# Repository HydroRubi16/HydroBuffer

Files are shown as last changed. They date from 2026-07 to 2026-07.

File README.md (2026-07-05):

# HydroBuffer
A Klipper based buffer to feed, unload and synchronize filament delivery to the toolhead  


The buffer consists of four parts:  
+ The housing (designed by me)  
+ Springloaded Turtle Neck, origninally modified by jakepfake, then modified by me for the buffer  
+ [Dual-Sensor WWBMG by DWTAS](https://github.com/Armchair-Heavy-Industries/A4T/tree/main/STL/WW-BMG%20for%20A4T/Dual%20Sensor)
+ A macro of some sort

*BOM*  
|Thing|Quantity|Notes|
|---|---|---|
|ECAS04|2|Need another for WWBMG, but follow that BOM|  
|Omron df2-l|2| Need another 2 for WWBMG, but follow that BOM|
|M3 heatsets|5| |
|M3 Square nuts|2|Need another 1 for WWBM, but follow that BOM|
|M2x10 self tapping screws|4|need another 4 for WWBMG, but follow that BOM|
|2.5mm ID PTFE|Enough||
|26awg wiring|enough| |
|M3 fasteners|enough|
|NOZZLE RESET SPRING|1|[found here](https://www.redwolfairsoft.com/accessories-springs-spring-guides-gbb-guns-modify-125-nozzle-reset-spring-for-tokyo-marui-g-series-2pcs-set.html) but other springs may work|

*Assembly*  

To assemble, it's pretty straight forward.  
1) Build WWBMG, per the instructions posted in that repo  
2) Build the TN per the instructions [here](https://www.armoredturtle.xyz/manual.html?manual=turtleneck&step=1). Leave the wiring long, and put the spring in place like the image below
3) Install the M3 heatset and 2x M3 square nuts  
4) Install the TN into the housing; use 4x M3 fasteners through the bottom of the housing
5) Install a length of 2.5mm ID PTFE tube through the housing, into the TN. Hold the TN plunger fully compressed,
slide in the PTFE until it stops, then cut the PTFE to be SLIGHTLY proud of the housing  
6) Install the WWBMG and route the wiring along the side of the houseing, above the TN switch wiring
7) Install the lid by pulling the wiring through the opening, and attaching the lid to the housing using a
   M3x8 SHCS on the end of the lid, and an M3x6 BHCS on the top

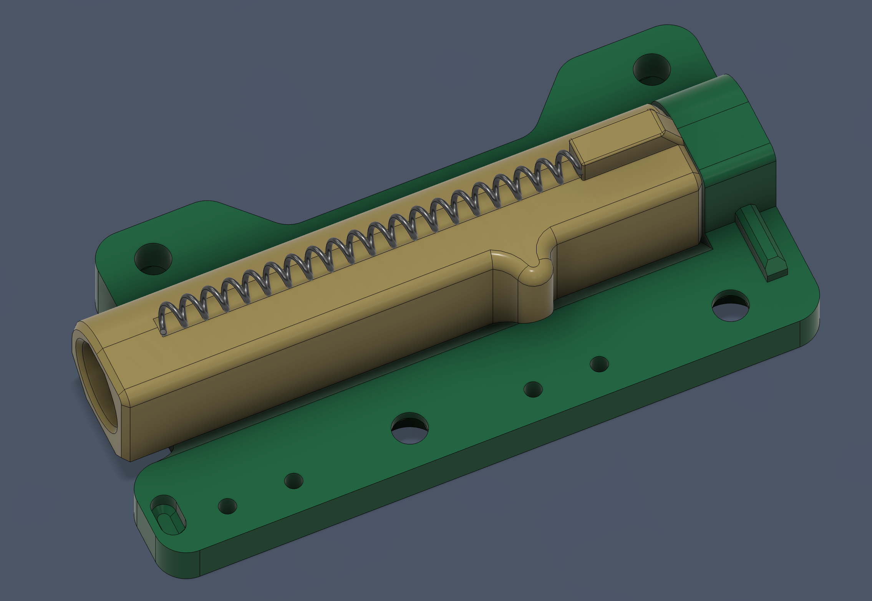
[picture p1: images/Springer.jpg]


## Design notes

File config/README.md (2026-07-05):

# Klipper Config  

Please note, this is only 1 option. There are many other macros that exist for this functionality, this is just what works for me. I load my filment with the hotend cold. If you chose to use this config, there are several parameters you will need to update:  

  + Switch pins
  + Secondary Extruder pins and config
  + Rotation_distance
  + Extrusion distances (speeds should be good/safe)
  + You will need to add this to your PRINT_START macro to reset the buffer before a print:

    SET_EXTRUDER_ROTATION_DISTANCE EXTRUDER=buffer DISTANCE=22.811

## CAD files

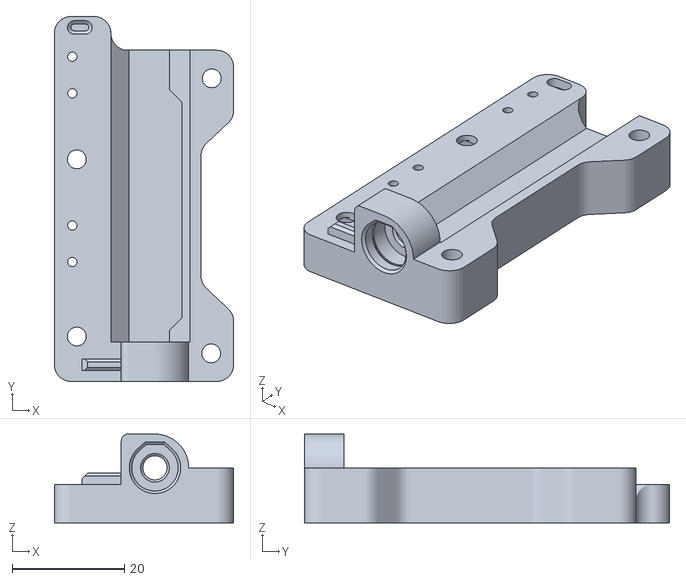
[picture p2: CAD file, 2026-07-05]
STLs/TN_bottom.stl
31.9 x 64.9 x 15.8

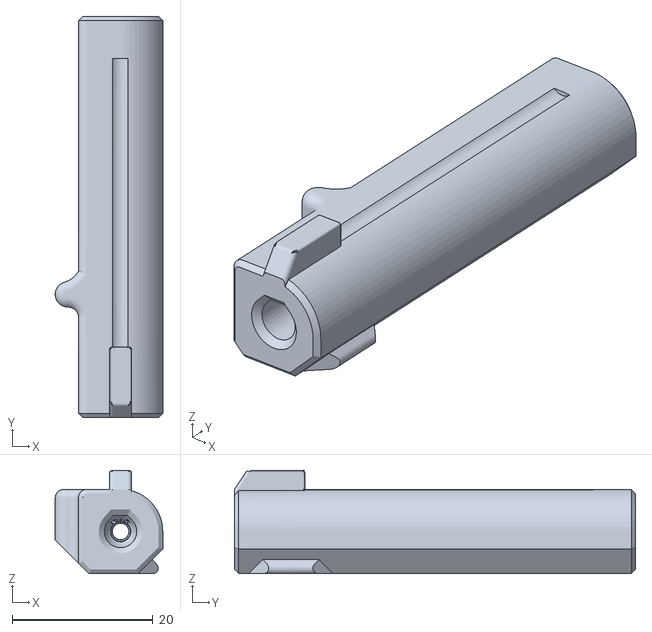
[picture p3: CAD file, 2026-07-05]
STLs/TN_neck.stl
15.3 x 57.0 x 14.7

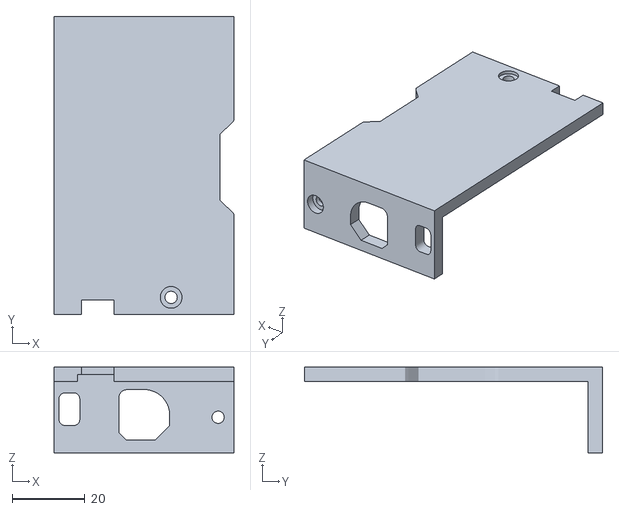
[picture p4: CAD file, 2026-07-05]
STLs/buffer_lid.stl
49.6 x 82.1 x 23.6

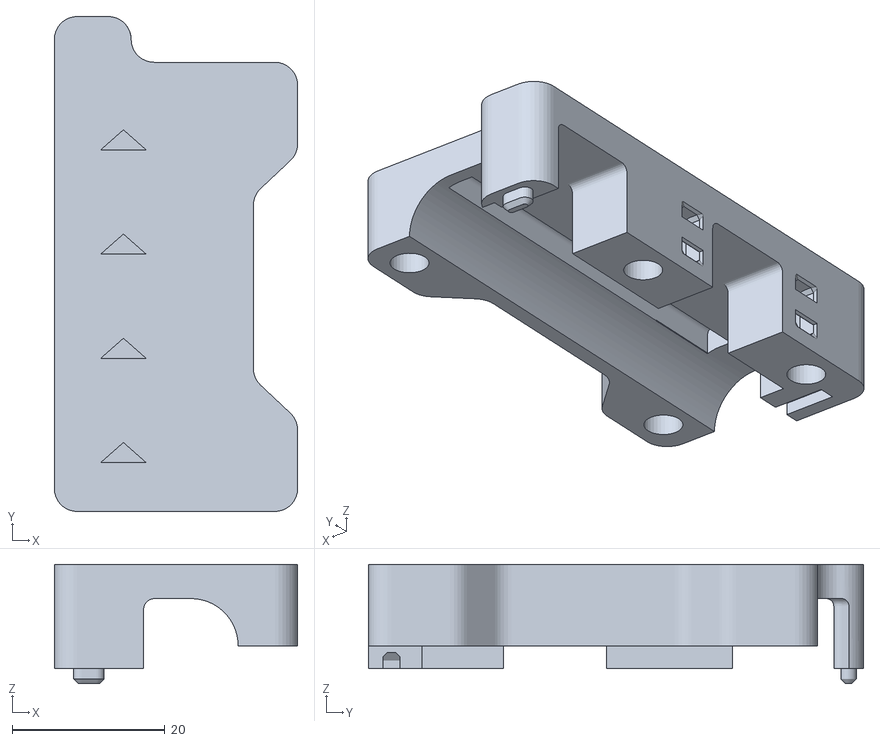
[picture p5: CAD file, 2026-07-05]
STLs/TN_top.stl
31.9 x 64.9 x 15.6

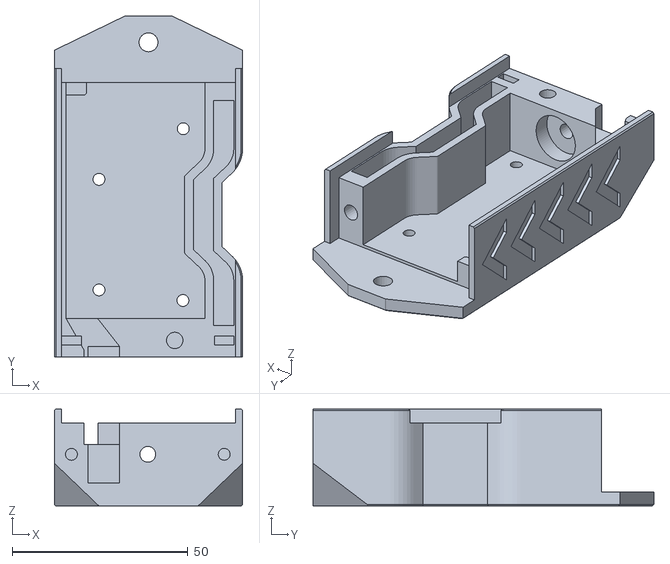
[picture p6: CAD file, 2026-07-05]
STLs/buffer_body.stl
53.6 x 97.1 x 27.6

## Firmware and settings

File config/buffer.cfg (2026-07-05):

[force_move]
enable_force_move: True

############################################################
# FILAMENT SWITCH SENSORS
############################################################

[filament_switch_sensor Enter]
switch_pin: ^PF10
pause_on_runout: False
insert_gcode: LOAD_FILAMENT_START

[filament_switch_sensor Exit]
switch_pin: ^PC0
pause_on_runout: False

[filament_switch_sensor Trail]
switch_pin: ^PB15
pause_on_runout: False

[filament_switch_sensor Lead]
switch_pin: ^PB14
pause_on_runout: False


[duplicate_pin_override]
pins: PB14, PB15

[gcode_button _TRAIL_TRIGGER]
pin: ^PB15
press_gcode: 
    {% if printer.print_stats.state == "printing" %}
        SET_EXTRUDER_ROTATION_DISTANCE EXTRUDER=buffer DISTANCE=22.00
        RESPOND MSG="BUFFER: Fully Compressed" 
        M117 Buffer fully compressed   
    {% endif %}
debounce_delay: 1

[gcode_button _LEAD_TRIGGER]
pin: ^PB14
press_gcode: 
    {% if printer.print_stats.state == "printing" %}
        SET_EXTRUDER_ROTATION_DISTANCE EXTRUDER=buffer DISTANCE=23.5
        RESPOND MSG="BUFFER: Extended" 
        M117 Buffer fully extended
    {% endif %}
debounce_delay: 1



############################################################
# SECONDARY EXTRUDER - BUFFER
############################################################
[extruder_stepper buffer]
extruder: extruder
step_pin: !PC13
dir_pin: !PC14
enable_pin: !PE6
microsteps: 32 
rotation_distance: 22.811
gear_ratio: 50:10
full_steps_per_rotation: 200


[tmc2209 extruder_stepper buffer]
uart_pin: PG14
interpolate: false
run_current: 0.60
sense_resistor: 0.110
stealthchop_threshold: 0

############################################################
[save_variables]
filename: ~/printer_data/config/saved_variables.cfg
############################################################

############################################################
# FILAMENT LOAD STATE HOLDER
############################################################

[gcode_macro _FILAMENT_LOAD_STATE]
variable_loading: False
variable_stage1_traveled: 0
variable_stage3_traveled: 0
gcode:
    # State holder only, not called directly

############################################################
# LOAD FILAMENT START
# Triggered by Enter sensor insert_gcode
############################################################

[gcode_macro LOAD_FILAMENT_START]
description: "Triggered by Enter sensor - begins filament load sequence"
gcode:
    SET_TMC_CURRENT STEPPER=buffer CURRENT=0.80
    {% set svv = printer.save_variables.variables %}
    {% set filament_status = svv.filament_status | default('unloaded') %}

    {% if filament_status == 'loaded' %}
        RESPOND MSG="LOAD: Filament already loaded - ignoring trigger"

    {% elif printer["gcode_macro _FILAMENT_LOAD_STATE"].loading == False %}
        SAVE_VARIABLE VARIABLE=filament_status VALUE='"loading"'
        SET_GCODE_VARIABLE MACRO=_FILAMENT_LOAD_STATE VARIABLE=loading VALUE=True
        SET_GCODE_VARIABLE MACRO=_FILAMENT_LOAD_STATE VARIABLE=stage1_traveled VALUE=0
        SET_GCODE_VARIABLE MACRO=_FILAMENT_LOAD_STATE VARIABLE=stage3_traveled VALUE=0
        RESPOND MSG="LOAD: Filament detected at Enter - starting Stage 1 slow feed"
        M117 Stage 1: Slow feed to Exit sensor...
        _FILAMENT_LOAD_STAGE1

    {% else %}
        RESPOND MSG="LOAD: Already loading, ignoring trigger"
    {% endif %}

############################################################
# STAGE 1: Kick off slow feed loop to Exit sensor
############################################################

[gcode_macro _FILAMENT_LOAD_STAGE1]
description: "Kick off Stage 1 delayed_gcode loop"
gcode:
    SET_GCODE_VARIABLE MACRO=_FILAMENT_LOAD_STATE VARIABLE=stage1_traveled VALUE=0
    RESPOND MSG="LOAD: Stage 1 starting..."
    UPDATE_DELAYED_GCODE ID=_STAGE1_LOOP DURATION=0.1

############################################################
# STAGE 1 LOOP: 2mm at a time until Exit sensor triggers
# Max 50mm before jam abort - tune to your buffer size
############################################################

[delayed_gcode _STAGE1_LOOP]
gcode:
    {% set traveled = printer["gcode_macro _FILAMENT_LOAD_STATE"].stage1_traveled %}
    {% set max_dist = 50 %}
    {% set step = 2 %}
    {% set velocity = 10 %}

    {% if printer['filament_switch_sensor Exit'].filament_detected == True %}
        RESPOND MSG="LOAD: Exit sensor triggered at {traveled}mm - starting Stage 2"
        M117 Stage 2: Fast feed fixed distance...
        _FILAMENT_LOAD_STAGE2

    {% elif traveled >= max_dist %}
        RESPOND MSG="LOAD ERROR: Exit sensor not triggered after {traveled}mm - possible jam! Aborting."
        M117 LOAD ERROR - Check filament!
        _FILAMENT_LOAD_ABORT

    {% else %}
        FORCE_MOVE STEPPER="extruder_stepper buffer" DISTANCE={step} VELOCITY={velocity}
        SET_GCODE_VARIABLE MACRO=_FILAMENT_LOAD_STATE VARIABLE=stage1_traveled VALUE={ traveled + step }
        UPDATE_DELAYED_GCODE ID=_STAGE1_LOOP DURATION=0.1
    {% endif %}

############################################################
# STAGE 2: Fast feed fixed distance to extruder gears
############################################################

[gcode_macro _FILAMENT_LOAD_STAGE2]
description: "Fast feed fixed distance toward toolhead"
variable_fast_distance: 875 #Need to test the length you need
variable_velocity: 150 #Tune this
variable_accel: 500 #Tune this
gcode:
    RESPOND MSG="LOAD: Stage 2 fast feed {fast_distance}mm at {velocity}mm/s"
    FORCE_MOVE STEPPER="extruder_stepper buffer" DISTANCE={fast_distance} VELOCITY={velocity} ACCEL={accel}
    RESPOND MSG="LOAD: Stage 2 complete - starting Stage 3 slow feed"
    M117 Stage 3: Slow feed to Lead sensor...
    _FILAMENT_LOAD_STAGE3

############################################################
# STAGE 3: Kick off slow feed loop to Lead sensor
############################################################

[gcode_macro _FILAMENT_LOAD_STAGE3]
description: "Kick off Stage 3 delayed_gcode loop"
gcode:
    SET_GCODE_VARIABLE MACRO=_FILAMENT_LOAD_STATE VARIABLE=stage3_traveled VALUE=0
    RESPOND MSG="LOAD: Stage 3 starting..."
    UPDATE_DELAYED_GCODE ID=_STAGE3_LOOP DURATION=0.1

############################################################
# STAGE 3 LOOP: 2mm at a time until Lead sensor triggers
# Max 100mm before jam abort - tune to your buffer size
############################################################

[delayed_gcode _STAGE3_LOOP]
gcode:
    {% set traveled = printer["gcode_macro _FILAMENT_LOAD_STATE"].stage3_traveled %}
    {% set max_dist = 100 %} #Max distance for ramming, for safety and stuff
    {% set step = 2 %}
    {% set velocity = 6 %}

    {% if printer['filament_switch_sensor Lead'].filament_detected == True %}
        RESPOND MSG="LOAD: Lead sensor triggered at {traveled}mm - starting Stage 4 purge"
        M117 Stage 4: Purging 50mm...
        _FILAMENT_LOAD_STAGE4

    {% elif traveled >= max_dist %}
        RESPOND MSG="LOAD ERROR: Lead sensor not triggered after {traveled}mm - possible jam! Aborting."
        M117 LOAD ERROR - Check filament!
        _FILAMENT_LOAD_ABORT

    {% else %}
        FORCE_MOVE STEPPER="extruder_stepper buffer" DISTANCE={step} VELOCITY={velocity}
        SET_GCODE_VARIABLE MACRO=_FILAMENT_LOAD_STATE VARIABLE=stage3_traveled VALUE={ traveled + step }
        UPDATE_DELAYED_GCODE ID=_STAGE3_LOOP DURATION=0.1
    {% endif %}

###################################################################
# STAGE 4: Final load to HE cold side using FORCE_MOVE on extruder
###################################################################

[gcode_macro _FILAMENT_LOAD_STAGE4]
description: "Final 50mm load to HE cold side"
variable_purge_distance: 50     #Change for your toolhead, tune this
variable_velocity: 10           #Tune this
gcode:
    RESPOND MSG="LOAD: Purging {purge_distance}mm..."
    FORCE_MOVE STEPPER=extruder DISTANCE={purge_distance} VELOCITY={velocity}
    SET_GCODE_VARIABLE MACRO=_FILAMENT_LOAD_STATE VARIABLE=loading VALUE=False
    SAVE_VARIABLE VARIABLE=filament_status VALUE='"loaded"'
    SET_FILAMENT_SENSOR SENSOR=Enter ENABLE=0
    SET_TMC_CURRENT STEPPER=buffer CURRENT=0.60
    RESPOND MSG="LOAD: Complete! Filament status saved as 'loaded'. Enter sensor disabled."
    M117 Filament loaded!

[gcode_macro _FILAMENT_LOAD_ABORT]
description: "Abort filament load and reset state"
gcode:
    SET_GCODE_VARIABLE MACRO=_FILAMENT_LOAD_STATE VARIABLE=loading VALUE=False
    SET_GCODE_VARIABLE MACRO=_FILAMENT_LOAD_STATE VARIABLE=stage1_traveled VALUE=0
    SET_GCODE_VARIABLE MACRO=_FILAMENT_LOAD_STATE VARIABLE=stage3_traveled VALUE=0
    SAVE_VARIABLE VARIABLE=filament_status VALUE='"unloaded"'
    SET_FILAMENT_SENSOR SENSOR=Enter ENABLE=1
    RESPOND MSG="LOAD: Aborted - check filament for jam!"
    M117 Load aborted - check filament!
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
